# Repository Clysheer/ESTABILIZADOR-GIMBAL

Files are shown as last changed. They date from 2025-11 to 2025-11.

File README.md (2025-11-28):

# ESTABILIZADOR-GIMBAL

Proyecto de gimbal de tres ejes con Arduino Nano, IMU MPU6050 y servos SG90. Incluye PCB diseñada, firmware en C y estructura 3D en PLA. Estabiliza una cámara ligera compensando ±45° con un error menor a 3°, validando el control PID implementado.

## Introducción

El objetivo principal de este trabajo fue diseñar y construir un gimbal electrónico de tres ejes capaz de mantener una cámara estable, compensando los movimientos involuntarios del usuario. Los gimbals son ampliamente utilizados en drones, cámaras portátiles y equipos de filmación profesional, debido a su capacidad para estabilizar la imagen incluso en condiciones dinámicas. La motivación para desarrollar este proyecto surgió de la necesidad creciente de capturar tomas fluidas y sin vibraciones, especialmente en aplicaciones audiovisuales y sistemas aéreos no tripulados.

El desarrollo del gimbal permitió integrar y aplicar múltiples conocimientos adquiridos a lo largo de la tecnicatura, tales como electrónica analógica y digital, diseño de circuitos impresos (PCB), programación de microcontroladores, control automático y procesamiento de señales provenientes de sensores. Este enfoque interdisciplinario hizo posible comprender de manera global cómo distintos sistemas electrónicos pueden trabajar en conjunto para resolver un problema real.

Desde un punto de vista teórico, la construcción del gimbal implicó estudiar conceptos fundamentales de análisis y control de sistemas dinámicos. Para lograr una estabilización eficiente fue necesario comprender el funcionamiento de sensores inerciales (IMU), específicamente el MPU6050, que combina un acelerómetro y un giroscopio de 3 ejes. Estos sensores permiten obtener información sobre la aceleración y la velocidad angular del dispositivo, datos que deben ser filtrados y procesados para estimar correctamente la orientación de la cámara. Se analizaron filtros complementarios y técnicas básicas de fusión sensorial para mejorar la precisión y reducir el ruido de las mediciones.

Otro aspecto central del estudio fue el control PID (Proporcional, Integral y Derivativo), un algoritmo clásico en sistemas de control realimentados. Fue necesario comprender su funcionamiento, las funciones de cada uno de sus términos y cómo su ajuste influye directamente en la estabilidad y velocidad de respuesta del sistema. Se realizaron análisis teóricos sobre estabilidad, amortiguamiento, respuesta al escalón y efectos de la sintonización de parámetros Kp, Ki y Kd. Este controlador permitió corregir en tiempo real la diferencia entre la posición deseada y la posición medida, generando las señales necesarias para ajustar los ángulos de los servomotores.

Asimismo, se estudiaron los principios de funcionamiento de los servomotores, particularmente su control mediante modulación por ancho de pulso (PWM). Se analizaron sus limitaciones mecánicas y eléctricas, torque disponible, velocidad de respuesta y resolución angular. También se evaluaron distintos configuraciones mecánicas y de soporte para garantizar la correcta transmisión del movimiento.

La estructura mecánica del gimbal se diseñó mediante software CAD y luego fue fabricada mediante impresión 3D en PLA. Esto permitió estudiar conceptos de diseño mecánico, peso, distribución de masa, centro de gravedad y rigidez estructural, factores claves para garantizar que el sistema pueda estabilizarse correctamente sin introducir vibraciones.

En conjunto, este proyecto representó una integración completa de teoría y práctica, abarcando áreas como control automático, electrónica digital, diseño de hardware, programación embebida y fabricación mecánica. El resultado final fue un sistema funcional capaz de estabilizar una cámara ligera, demostrando la importancia de la combinación entre conocimientos teóricos y aplicaciones prácticas.

### Objetivos específicos
- Diseñar y construir el circuito de control de los motores, integrando los servomotores y la electrónica necesaria para su funcionamiento.
- Adquirir y procesar los datos del sensor inercial MPU6050 mediante comunicación I2C.
- Implementar un algoritmo de control PID capaz de mantener la posición estable en los tres ejes.
- Diseñar, modelar e imprimir en 3D la estructura mecánica que sostiene la cámara y los motores.
- Integrar hardware, software y mecánica en un único sistema funcional.

Se realizaron ajustes para poder tener los 3 servos bien colocados.

## Descripción del proyecto

### ¿Qué es un Gimbal?

Un gimbal es un sistema de suspensión que permite mantener un objeto (como una cámara) estable y nivelado mientras se mueve. Utiliza motores o servomotores para contrarrestar los movimientos no deseados y estabilizar el objeto en cuestión. En este caso, el gimbal de 3 ejes se utiliza para estabilizar una cámara pequeña o dispositivo similar durante los movimientos en los tres ejes principales: Yaw (giro horizontal), Pitch (inclinación vertical) y Roll (rotación lateral).

En lugar de usar un sistema mecánico pesado, un gimbal moderno utiliza sensores electrónicos y motores controlados electrónicamente para realizar ajustes en tiempo real. Esto permite una estabilización más precisa y dinámica, ideal para aplicaciones como la grabación de videos o fotografía aérea, donde la estabilidad es crucial.

### Componentes principales del Gimbal

#### Servos
En este proyecto, se usan tres servomotores para controlar el movimiento de la cámara en los tres ejes. Los servos son motores de corriente continua con un mecanismo de control que permite ajustar su ángulo de forma precisa. Cada servo se controla mediante una señal de modulación por ancho de pulso (PWM), donde el ancho del pulso determina el ángulo del servo.

Los servos tienen la ventaja de ser fáciles de controlar mediante una señal PWM, lo que los hace ideales para proyectos como este, donde se requiere un control preciso de los movimientos. Sin embargo, los servos también tienen limitaciones en cuanto a la velocidad y torque, lo que debe ser considerado al diseñar el gimbal.

#### MPU6050 (Sensor IMU)
El MPU6050 es un sensor de movimiento que combina un acelerómetro de 3 ejes y un giroscopio de 3 ejes. Este sensor es capaz de medir la aceleración y la velocidad angular en los tres ejes del espacio (X, Y y Z). Se utiliza para detectar el movimiento de la cámara y proporcionar información precisa sobre su orientación en el espacio.

- **Acelerómetro**: mide la aceleración en los tres ejes, lo que ayuda a detectar la inclinación de la cámara con respecto a la gravedad.
- **Giroscopio**: mide la velocidad angular, es decir, la rotación de la cámara en cada uno de los ejes.

La información de estos dos sensores se procesa para calcular la orientación actual de la cámara. La combinación de ambos datos (acelerómetro y giroscopio) permite tener una estimación más precisa del movimiento, ya que cada sensor compensa las limitaciones del otro.

En el proyecto, el MPU6050 se conecta al Arduino a través del protocolo I2C, lo que permite transmitir los datos del sensor con solo dos cables: uno para la señal de reloj (SCL) y otro para la señal de datos (SDA). Estos datos se usan para calcular el ángulo de inclinación de la cámara y se pasan al algoritmo de control PID que ajusta los servos para mantener la estabilización.

#### Arduino
El Arduino es el cerebro del sistema, responsable de recibir los datos del sensor MPU6050 y procesarlos para calcular los ajustes que deben realizarse en los servos. El Arduino, en este caso, actúa como un controlador en tiempo real que implementa un algoritmo de control PID para mantener los ángulos de la cámara estables.

El microcontrolador Arduino UNO se usa por su simplicidad, facilidad de programación y la amplia cantidad de librerías disponibles, que simplifican el trabajo con el sensor MPU6050 y el control de los servos. A través de las señales PWM generadas por el Arduino, se controla el ángulo de cada servo, asegurando que la cámara mantenga la orientación deseada en cada momento.

#### Step-up Converter (Ajuste de voltaje)
Para alimentar la placa del Arduino y los servos, se utiliza un step-up converter. Dado que los servos y el Arduino requieren una tensión de 5V, pero el sistema está alimentado por una batería Li-Po de 3.7V, es necesario usar un step-up para elevar la tensión de la batería hasta los 5V necesarios para el funcionamiento del sistema.

Un step-up converter (convertidor elevador) es un tipo de fuente de alimentación DC-DC que convierte una entrada de baja tensión (en este caso, 3.7V) a una salida de mayor tensión (5V). Esto es crucial, ya que los servos y el Arduino no funcionarían correctamente con 3.7V, ya que ambos requieren una tensión constante de 5V. El step-up también asegura que la energía se entregue de forma eficiente, sin perder demasiada potencia.

### Control PID
El control PID (Proporcional, Integral, Derivativo) es un algoritmo que se utiliza para mantener la cámara en una posición estable. Este tipo de control en lazo cerrado ajusta continuamente la salida (en este caso, el movimiento de los servos) en función de la diferencia entre el valor actual y el valor deseado.

- **Proporcional (P)**: Compara la diferencia (error) entre el ángulo actual y el deseado. Cuanto mayor es el error, mayor será la corrección aplicada.
- **Integral (I)**: Suma el error a lo largo del tiempo, lo que ayuda a corregir pequeños desajustes acumulados.
- **Derivativo (D)**: Analiza la tasa de cambio del error, ayudando a reducir oscilaciones y hacer que el sistema sea más estable.

El objetivo del PID es ajustar los servos en tiempo real para que la cámara mantenga la orientación correcta, minimizando el error de estabilización. Los parámetros Kp, Ki y Kd se ajustan mediante pruebas para lograr una respuesta estable y rápida.

### Funcionamiento del Gimbal
El proceso de estabilización del gimbal funciona de la siguiente manera:

1. **Lectura del sensor**: El MPU6050 mide constantemente la aceleración y la velocidad angular de la cámara.
2. **Cálculo de los ángulos**: Los datos del sensor se procesan en el Arduino para calcular el ángulo de inclinación en los tres ejes.
3. **Control PID**: El algoritmo PID calcula el error entre el ángulo actual y el deseado (normalmente 0° en todos los ejes).
4. **Ajuste de los servos**: El Arduino ajusta los servos mediante señales PWM para contrarrestar cualquier movimiento no deseado y estabilizar la cámara.

### Limitaciones y Mejoras
El uso de servos para este tipo de proyecto tiene algunas limitaciones, como el torque limitado y la velocidad de respuesta. Si los movimientos son muy rápidos o fuertes, los servos podrían no ser lo suficientemente rápidos para corregir la orientación a tiempo. Sin embargo, para cámaras pequeñas y movimientos suaves, los servos proporcionan una solución económica y fácil de implementar.

Como posible mejora, se podría usar motores brushless o stepper motors en lugar de servos, ya que ofrecen mayor torque y velocidad. Sin embargo, esto complicaría el diseño y el control del sistema.

### Lista de componentes y precios estimados
- Arduino Nano - 8000
- MPU6050 - 4500
- 3 Servomotores - 2300 c/u
- Step-up LM2596 - 2900
- 4 JST - 200 c/u
- Borneras - 100 c/u
- Pineras hembra - 1800
- Filamento PLA para diseño 3D - 19.000 x kg (50 grs usados)
- Tornillos - 500
- Cables de interconexión - 2000
- Batería de litio 3,7v - 3500
- **Precio estimado: 27.000 a 30.000**

## SOFTWARE

El software desarrollado para el gimbal electrónico de 3 ejes se encarga de leer los datos del sensor inercial MPU6050, procesarlos mediante algoritmos de filtrado, calcular los ángulos de orientación y ejecutar un control PID para ajustar la posición de los servomotores SG90 en tiempo real. El objetivo del software es garantizar que la cámara permanezca estable aun cuando el usuario realice movimientos bruscos.

El firmware se implementó en lenguaje C/C++ utilizando el entorno de Arduino IDE y emplea librerías específicas para el manejo del sensor y los servos. Toda la lógica del control está optimizada para funcionar en un microcontrolador de recursos limitados como el Arduino Nano.

### Arquitectura general del software
El software se divide en los siguientes módulos principales:
1. Inicialización del sistema
2. Lectura del sensor MPU 6050 (acelerómetro + giroscopio)
3. Procesamiento y filtrado de datos (filtro complementario)
4. Cálculo de los ángulos de orientación (Roll, Pitch, Yaw)
5. Control PID para cada eje
6. Generación de señales PWM para los servomotores
7. Bucle principal (loop) en tiempo real

Diagrama de flujo

### Descripción detallada de cada bloque

#### 3.1. Inicialización del sistema
En esta etapa se configuran:
- La comunicación I2C (Wire.h)
- La velocidad de muestreo del MPU6050
- Los pines y librerías de los servos
- Variables internas del PID
- Temporizadores para cálculos en tiempo real

El sistema queda listo para funcionar dentro del loop principal.

#### 3.2. Lectura del sensor MPU6050
El sensor proporciona:
- Aceleración (Ax, Ay, Az)
- Velocidad angular (Gx, Gy, Gz)

La lectura se realiza a través de I2C y se normaliza a unidades físicas:
- Acelerómetro → g (9.81 m/s²)
- Giroscopio → °/s (grados por segundo)

Estas señales suelen contener ruido, por eso necesitan filtrado.

#### 3.3. Filtrado y Fusión de Datos
Para obtener una estimación precisa de los ángulos se utiliza un filtro complementario, que combina:
- Los datos estables del acelerómetro
- La rapidez y suavidad del giroscopio

El filtro realiza:
Ángulo = 0.98*(Ángulo + gyro*dt) + 0.02*(Accel)

Este método reduce vibraciones y evita errores acumulados.

#### 3.4. Cálculo de Ángulos (Roll, Pitch y Yaw)
Del acelerómetro se obtienen roll y pitch mediante trigonometría:
- Roll = atan2(Ay, Az)
- Pitch = atan2(-Ax, sqrt(Ay² + Az²))

Yaw se obtiene integrando el giroscopio Gz.
Cada ángulo se estabiliza mediante el filtro complementario.

#### 3.5. Control PID
El PID compara la posición actual (sensor) con la deseada (0° para estabilización).
Para cada eje se calcula:
- Error: diferencia entre ángulo deseado y ángulo real
- P: corrige el error instantáneo
- I: acumula errores pequeños
- D: suaviza y evita oscilaciones

El PID entrega un valor corregido que indica cuánto debe moverse cada servo.

#### 3.6. Señales PWM a los Servomotores
Arduino genera pulsos PWM con:
- Frecuencia: 50 Hz
- Ancho del pulso: 500–2500 µs

El ancho del pulso define la posición del servo.
Ejemplo:
- 1000 µs → -45º
- 1500 µs → 0º
- 2000 µs → +45º

#### 3.7. Loop principal
Se ejecuta unas 200 a 400 veces por segundo, realizando:
1. Lectura MPU6050
2. Filtrado de señales
3. PID
4. PWM
5. Estabilización

Esto permite una respuesta rápida del gimbal.

### Flujo de funcionamiento del software (texto para informe)
1. El sistema inicia y configura todos los módulos.
2. El microcontrolador lee las mediciones del MPU6050.
3. Los datos se filtran para obtener ángulos limpios.
4. Se calcula la orientación de la cámara.
5. El PID determina cuánto corregir la posición.
6. Los servos se ajustan mediante PWM.
7. El proceso se repite en tiempo real.

### Código PID

```cpp
#include <Wire.h>
#include <Servo.h>
#include "I2Cdev.h"
#include "MPU6050.h"

MPU6050 mpu;
Servo servoRoll, servoPitch, servoYaw;

// Ángulos filtrados
float roll = 0, pitch = 0, yaw = 0;

// Offsets del giroscopio (se calibran en setup)
float gyroXoffset = 0, gyroYoffset = 0, gyroZoffset = 0;

// Setpoints (posición deseada del gimbal)
float setpointRoll = 0;
float setpointPitch = 0;
float setpointYaw = 0;

// Variables PID
float errorRoll, errorPitch, errorYaw;
float prevErrorRoll = 0, prevErrorPitch = 0, prevErrorYaw = 0;
float integralRoll = 0, integralPitch = 0, integralYaw = 0;

// Ganancias PID (ajustar según pruebas)
float Kp = 2.0;
float Ki = 0.5;
float Kd = 1.0;

unsigned long lastTime = 0;
float dt = 0.01;

// Factor del filtro complementario (0.98 → giroscopio domina, 0.02 → acelerómetro corrige)
const float alpha = 0.98;

void setup() {
    Serial.begin(9600);
    Wire.begin();
    
    // Inicializar MPU6050
    Serial.println("Inicializando MPU6050...");
    mpu.initialize();
    if (!mpu.testConnection()) {
        Serial.println("Error: no se detecta MPU6050!");
        while (1);
    }
    
    // Calibrar giroscopio (promedio en reposo)
    Serial.println("Calibrando giroscopio...");
    long gxSum = 0, gySum = 0, gzSum = 0;
    for (int i = 0; i < 2000; i++) {
        int16_t ax, ay, az, gx, gy, gz;
        mpu.getMotion6(&ax, &ay, &az, &gx, &gy, &gz);
        gxSum += gx;
        gySum += gy;
        gzSum += gz;
        delay(2);
    }
    gyroXoffset = gxSum / 2000.0;
    gyroYoffset = gySum / 2000.0;
    gyroZoffset = gzSum / 2000.0;
    Serial.println("Calibración completa.");
    
    // Servos
    servoRoll.attach(9);
    servoPitch.attach(10);
    servoYaw.attach(11);
    servoRoll.write(90);
    servoPitch.write(90);
    servoYaw.write(90);
    
    lastTime = millis();
}

void loop() {
    unsigned long now = millis();
    dt = (now - lastTime) / 1000.0;
    if (dt <= 0) dt = 0.01;
    lastTime = now;
    
    // Leer datos del MPU6050
    int16_t ax, ay, az, gx, gy, gz;
    mpu.getMotion6(&ax, &ay, &az, &gx, &gy, &gz);
    
    // Convertir giroscopio a º/s (sensibilidad: 131 LSB/(º/s))
    float gyroXrate = (gx - gyroXoffset) / 131.0;
    float gyroYrate = (gy - gyroYoffset) / 131.0;
    float gyroZrate = (gz - gyroZoffset) / 131.0;
    
    // Calcular ángulos con acelerómetro
    float accPitch = atan2(ax, sqrt(ay * ay + az * az)) * 180.0 / PI;
    float accRoll  = atan2(ay, sqrt(ax * ax + az * az)) * 180.0 / PI;
    
    // Filtro complementario
    pitch = alpha * (pitch + gyroXrate * dt) + (1 - alpha) * accPitch;
    roll  = alpha * (roll - gyroYrate * dt) + (1 - alpha) * accRoll;
    yaw += gyroZrate * dt; // yaw solo con giroscopio (deriva un poco con el tiempo)
    
    // --- PID Roll ---
    errorRoll = setpointRoll - roll;
    integralRoll += errorRoll * dt;
    float derivativeRoll = (errorRoll - prevErrorRoll) / dt;
    float outputRoll = Kp * errorRoll + Ki * integralRoll + Kd * derivativeRoll;
    prevErrorRoll = errorRoll;
    
    // --- PID Pitch ---
    errorPitch = setpointPitch - pitch;
    integralPitch += errorPitch * dt;
    float derivativePitch = (errorPitch - prevErrorPitch) / dt;
    float outputPitch = Kp * errorPitch + Ki * integralPitch + Kd * derivativePitch;
    prevErrorPitch = errorPitch;
    
    // --- PID Yaw ---
    errorYaw = setpointYaw - yaw;
    integralYaw += errorYaw * dt;
    float derivativeYaw = (errorYaw - prevErrorYaw) / dt;
    float outputYaw = Kp * errorYaw + Ki * integralYaw + Kd * derivativeYaw;
    prevErrorYaw = errorYaw;
    
    // Convertir a servo (90 = centro)
    int servoRollVal  = constrain(90 + outputRoll, 0, 180);
    int servoPitchVal = constrain(90 + outputPitch, 0, 180);
    int servoYawVal   = constrain(90 + outputYaw, 0, 180);
    
    servoRoll.write(servoRollVal);
    servoPitch.write(servoPitchVal);
    servoYaw.write(servoYawVal);
    
    // Debug
    Serial.print("Roll: "); Serial.print(roll);
    Serial.print(" | Pitch: "); Serial.print(pitch);
    Serial.print(" | Yaw: "); Serial.print(yaw);
    Serial.print(" | S_R: "); Serial.print(servoRollVal);
    Serial.print(" | S_P: "); Serial.print(servoPitchVal);
    Serial.print(" | S_Y: "); Serial.println(servoYawVal);
    
    delay(10); // ~100 Hz
}
```

## Hardware

### DISEÑO ELECTRÓNICO Y ESQUEMÁTICO (MÓDULOS Y CIRCUITO PRINCIPAL)

Objetivo de la etapa: definir la arquitectura eléctrica del gimbal y generar el esquemático que interconecta MCU, IMU, drivers de potencia, alimentación y servos.

#### Módulos utilizados
- Microcontrolador: Arduino Nano (ATmega328P)
- IMU: MPU6050 (Acelerómetro + Giroscopio 3-ejes)
- Actuadores: 3 × Servomotores SG90 (PWM)
- Regulación: Step-up DC-DC (LM2596 o equivalente)
- Alimentación: Batería LiPo 1S (3.7 V)
- Conectores: JST 3/4 pines, pines hembra 2.54 mm
- Indicadores: LED de alimentación y pulsadores de calibración (opcional)

#### Esquema eléctrico (descripción para replicar)
- V_BAT → STEPUP_IN
- STEPUP_OUT 5V → RAIL_5V (alimentación para Arduino y servos)
- GND común a batería, step-up, servos y Arduino
- Arduino (5V) alimenta: VIN o 5V según modelo (en Nano usar pin 5V)
- MPU6050: SDA → A4 (I2C SDA), SCL → A5 (I2C SCL), VCC → 3.3V o 5V (según breakout) – usar 3.3V si es breakout sin regulador; comprobar tolerancias. GND → GND
- Servos: señal → pines PWM del Arduino (ej: D3, D5, D6), Vcc → RAIL_5V, GND → GND
- Condensadores de desacople: 100µF en entrada y salida del step-up, 0.1µF cerámico cerca del MCU y del IMU
- Fusible polímero o PTC en línea de batería (recomendado)

Aplicación: el esquema se usa para fabricar la PCB que interconecta todos los módulos con vías limpias, anclajes mecánicos para el ensamblado y header para conexión de la estructura 3D.

Esquemático PCB

### DESCRIPCIÓN DE CADA ETAPA DE CONSTRUCCIÓN

#### Etapa A — Montaje y prueba de la alimentación
- Módulo: Step-up LM2596, fusible PTC, conector batería.
- Schematic focal: entrada batería → PTC → condensadores → LM2596 → 5V rail → protecciones.
- Pruebas: medir 5V sin carga y con servos conectados; verificar rizado < 100 mV.
- Aplicación: suministrar energía estable a servos y MCU.

#### Etapa B — Comunicación y sensor IMU
- Módulo: MPU6050 (I2C).
- Schematic focal: pull-ups I2C, decoupling, y test pads.
- Pruebas: leer registros WHO_AM_I, comprobar aceleraciones en reposo.
- Aplicación: proveer mediciones de aceleración y velocidad angular.

#### Etapa C — Control y firmware básico
- Módulo: Arduino Nano + firmware base (I2C, lectura IMU, serial).
- Schematic focal: pines de programación, led de status.
- Pruebas: mostrar datos por Serial, verificar lecturas estables.
- Aplicación: plataforma de prueba para algoritmos.

#### Etapa D — Actuadores y control PID
- Módulo: 3× SG90, headers de servo, filtros de alimentación.
- Schematic focal: ruta de alimentación de servos y pines PWM.
- Pruebas: enviar ángulos de prueba, medir respuesta y tiempos.
- Aplicación: ajuste de Kp, Ki, Kd y verificación de comportamiento.

#### Etapa E — Integración mecánico-eléctrica
- Módulo: estructura 3D en PLA (soportes, anclajes de servos) y montaje final de PCB.
- Schematic focal: puntos de anclaje, orificios M3, distancias.
- Pruebas: montaje mecánico, balanceo de cargas, centrado de masas.
- Aplicación: ver comportamiento dinámico real.

#### Etapa F — Calibración, pruebas finales y documentación
- Módulo: software de calibración y parámetros finales, manual de usuario.
- Schematic focal: puntos de ajuste (trim) y header de calibración.
- Pruebas: medición de error final (<3°), endurance tests.
- Aplicación: entrega del proyecto y repositorio.

### ESPECIFICACIONES TÉCNICAS (DETALLADAS)

#### Especificaciones generales
- Ejes: 3 (Yaw, Pitch, Roll)
- Rango de corrección: ±45° (por eje)
- Error de estabilización: < 3° (según pruebas)
- Latencia de control objetivo: < 20 ms
- Tasa de muestreo IMU: 200–500 Hz
- Alimentación: 1S LiPo 3.7 V → Step-up a 5 V
- Consumo estimado: 500 mA (reposo) – hasta 2 A con 3 servos en carga

#### Componentes críticos y parámetros
- MPU6050: resolución ±2g/±250°/s (configurable)
- Servos SG90: torque 1.6–2.2 kg·cm, velocidad ~0.1 s/60°
- Step-up LM2596: efficiency ~80–90%, corriente máxima 3 A (con disipación adecuada)
- MCU: ATmega328P @16 MHz, memoria suficiente para PID y filtros

Especificaciones técnicas

## DISEÑO 3D EN FUSION 360 (PARA LA ESTRUCTURA EN PLA)

Objetivo: diseñar la estructura que aloje la cámara y los servos, permita montaje seguro y tenga puntos de anclaje para la PCB y la batería.

### Flujo en Fusion 360
1. Esbozo (Sketch): definir dimensiones base del soporte de cámara y ubicación de servos.
2. Modelado: extruir y crear cortes, añadir nervaduras para rigidez.
3. Soportes y anclajes: crear orificios M3 y bosses para inserción de tuercas empotradas.
4. Verificación de interferencias: usar la herramienta de assemble para montar servos y cámara y verificar colisiones.
5. Exportar: generar archivos STL por cada pieza y PDFs con dimensiones.

### Parámetros de diseño recomendados
- Espesor mínimo de paredes: 2.5–3 mm (para PLA estructural).
- Bosses para tuercas: altura 3–4 mm, diámetro 2 mm mayor que el tornillo.
- Holgura para encajes: 0.2–0.4 mm según precisión de impresora.
- Zona de montaje de servos: ajuste de 0.5–1 mm si el servo se inserta a presión.
- Anclajes para PCB: 4 puntos con separación

### Configuraciones de impresión (PLA) sugeridas
- Layer height: 0.20 mm
- Infill: 20% (rectilinear o gyroid para rigidez)
- Perímetro: 3 shells
- Temp extrusor: 200–210 °C (según filamento)
- Temp cama: 50–60 °C
- Velocidad: 40–60 mm/s
- Soportes: donde haya voladizos > 45°
- Post-procesado: lijado y, si es necesario, encolado con epoxi para uniones críticas

### Pruebas mecánicas
- Balanceo: colocar la cámara y medir centro de gravedad; ajustar contrapesos si hace falta
- Rigidez: ensayo de vibración manual y comprobar resonancias con la IMU (picos en frecuencia)

### Diseño Montado y finalizado
Diseño Final

### Proceso de diseño
Proceso de diseño

### Primer Prototipo
Primer Prototipo

### Diseño Final
Diseño Final

## Diagrama de gantt, reparto de tareas y tiempos
Diagrama de Gantt

## Conclusiones

El desarrollo del gimbal electrónico de tres ejes permitió integrar conocimientos de electrónica, programación, control, diseño 3D y fabricación de PCBs, culminando en un sistema funcional capaz de estabilizar una cámara ligera frente a movimientos no deseados. A lo largo del proyecto se logró implementar un sistema de control basado en un algoritmo PID, utilizando un sensor inercial MPU6050 y servomotores SG90, todo gestionado por un microcontrolador Arduino Nano.

La estructura mecánica se diseñó íntegramente en Fusion 360 y se imprimió en PLA, logrando un soporte liviano, rígido y adecuado para alojar los motores y la cámara. Por otro lado, el diseño y fabricación de la PCB en KiCad permitió reducir el cableado, mejorar la robustez del sistema y optimizar la distribución de cada componente electrónico.

Las pruebas realizadas mostraron que el sistema puede estabilizar la cámara con un error angular reducido, incluso frente a perturbaciones suaves y movimientos moderados. Si bien los servomotores tienen limitaciones de torque y velocidad, el desempeño general fue satisfactorio para las condiciones planteadas en este proyecto.

Este trabajo permitió consolidar habilidades adquiridas durante la tecnicatura, especialmente en control, sensores, programación, diseño CAD/CAE y prototipado electrónico. Asimismo, evidenció la importancia de integrar correctamente la mecánica, la electrónica y el software para obtener un sistema mecatrónico funcional y estable.

## Posibles mejoras y líneas de trabajo futuras

Si bien el gimbal cumple con los objetivos iniciales, existen varias mejoras que podrían implementarse para obtener un sistema más robusto, preciso y profesional:

### 1. Reemplazo del Arduino Nano por un ESP32
El ESP32 permitiría ampliar significativamente las capacidades del sistema:
- Mayor poder de procesamiento para ejecutar filtros más avanzados (Kalman, Madgwick).
- Control de motores más preciso gracias a PWM de alta resolución.
- Conectividad WiFi y Bluetooth para control remoto de la cámara.
- Posibilidad de transmisión de datos, telemetría o configuración desde una app.

Además, el mayor rendimiento del ESP32 permitiría implementar estabilización en tiempo real con menor latencia.

### 2. Uso de motores brushless con drivers gimbal (BGC)
Los servos SG90 son económicos pero limitados. Cambiar a motores brushless específicos para gimbal permitiría:
- Movimientos más suaves y continuos.
- Mayor torque disponible.
- Mayor velocidad de respuesta.
- Ausencia de vibraciones características del servo.

Con esto se lograría una estabilización semi-profesional comparable a la de los gimbals comerciales.

### 3. Implementación de un filtro de fusión de sensores avanzado
En lugar del filtrado simple basado en el MPU6050, se podría agregar:
- Filtro de Kalman
- Filtro Madgwick o Mahony

Esto mejoraría la precisión en la estimación de los ángulos, sobre todo en presencia de vibraciones o cambios bruscos.

### 4. Rediseño estructural optimizado
Usando Fusion 360 se podrían:
- Reducir peso aplicando aligeramientos en zonas no críticas.
- Mejorar la ergonomía del soporte.
- Aumentar la rigidez de la estructura para reducir resonancias.
- Integrar directamente soportes para cableado interno.

Un diseño más optimizado también permitiría mejorar la autonomía de la batería.

### 5. Integración de una batería de mayor capacidad y sistema de carga
Se recomienda:
- Agregar un módulo de carga TP4056.
- Mejorar la autonomía utilizando una batería Li-Ion 18650.
- Incorporar un indicador de nivel de batería en la PCB.

Esto haría que el gimbal sea más cómodo y seguro de utilizar.

### 6. Agregar modos de funcionamiento
El software podría ampliarse con funciones más completas:
- Modo "lock": mantiene fija la orientación.
- Modo "follow": sigue el movimiento del usuario suavizado.
- Modo panorámico: giro automático para capturas 360°.
- Configuración mediante Bluetooth o app móvil.

### 7. Integración de una cámara más pesada
Con un rediseño mecánico y motores más potentes se podría admitir:
- Cámaras deportivas (GoPro).
- Cámaras compactas.
- Módulos de visión artificial.

Esto ampliará notablemente su campo de aplicación.

## APÉNDICES

### Apéndice A – Manual de Usuario del Gimbal de 3 Ejes

#### 1. Introducción
Este manual tiene como objetivo indicar al usuario cómo utilizar correctamente el gimbal electrónico de 3 ejes diseñado en este proyecto. Incluye instrucciones de encendido, calibración, operación y mantenimiento básico.

#### 2. Componentes del sistema
El gimbal está compuesto por:
- Estructura 3D impresa (PLA) diseñada en Fusion 360.
- Microcontrolador Arduino Nano (o placa equivalente).
- Sensor inercial MPU6050 (acelerómetro + giroscopio).
- 3 servomotores SG90 para los ejes Pitch, Roll y Yaw.
- Placa PCB personalizada diseñada en KiCad.
- Convertidor Step-Up LM2596 (para elevar la tensión de la batería).
- Batería LiPo/Li-Ion 3.7 V.
- Cableado interno con conectores JST.

#### 3. Puesta en marcha

##### 3.1 Encendido
1. Conectar la batería al sistema.
2. Verificar que el LED del Arduino encienda.
3. Esperar 2–3 segundos para que el MPU6050 se inicialice.
4. Mantener el gimbal quieto mientras se calibra automáticamente.

##### 3.2 Calibración inicial
Durante los primeros segundos:
- El sistema toma valores base de aceleración y giro.
- El PID se ajusta a la postura inicial de la cámara.

Recomendación:
Colocar el gimbal en una superficie estable y evitar movimiento.

#### 4. Operación

##### 4.1 Movimientos
El gimbal estabiliza automáticamente los tres ejes:
- Pitch (inclinación vertical)
- Roll (rotación lateral)
- Yaw (rotación horizontal)

El usuario puede manipular la base mientras el sistema compensa movimientos involuntarios.

##### 4.2 Funcionamiento del sistema
El algoritmo PID calcula en tiempo real la diferencia entre:
- Ángulo deseado (0°)
- Ángulo real medido por el MPU6050

y ajusta los servos inmediatamente.

##### 4.3 Modo de uso recomendado
- Movimientos suaves → mejor estabilización.
- Evitar golpes o vibraciones excesivas.
- Mantener la cámara bien centrada en el soporte.
- No exceder el peso recomendado (ideal: cámaras pequeñas).

#### 5. Mantenimiento

##### 5.1 Mantenimiento eléctrico
- Verificar periódicamente soldaduras y conectores JST.
- Asegurarse de que el LM2596 entregue 5 V estables.
- No utilizar baterías hinchadas o dañadas.

##### 5.2 Mantenimiento mecánico
- Revisar tornillos y soportes 3D.
- Evitar exposición prolongada al sol (PLA puede deformarse).
- Aplicar suavemente lubricación siliconada en los servos si es necesario.

#### 6. Solución de problemas

| Problema | Causa probable | Solución |
|---|---|---|
| El gimbal vibra demasiado | Ganancias PID incorrectas | Ajustar Kp, Ki o Kd |
| Se inclina hacia un lado | Calibración incorrecta | Reiniciar con el gimbal quieto |
| Los servos hacen ruido continuo | Demasiado esfuerzo mecánico | Recentrar la cámara |
| No enciende | Sin alimentación | Revisar batería y LM2596 |
| Movimientos lentos | Servo dañado o bajo torque | Reemplazar servo SG90 |

#### 8. Seguridad
- No conectar la batería al revés.
- Evitar contacto con agua o humedad.
- No operar cerca de objetos frágiles o personas.
- Mantener fuera del alcance de niños.

## BIBLIOGRAFÍA

- Arduino. Arduino Nano Documentation. Arduino.cc.
- Bosch Sensortec. MPU6050 6-axis MotionTracking Device – Datasheet.
- KiCad Project. KiCad EDA Documentation. kicad.org.
- SG90 Micro Servo Motor. Technical Specifications – TowerPro.
- Texas Instruments. LM2596 Step-Down Voltage Regulator Datasheet.
- National Instruments. PID Theory Explained.
- O'Reilly Media. Make: Electronics – Learning Through Discovery.
- Z. Chen & Others. Fundamentals of Inertial Navigation and Inertial Sensors.
- Autodesk. Fusion 360 User Manual. autodesk.com.
- Sebastian Madgwick. An efficient orientation filter for inertial/magnetic sensor arrays.
- R. Isermann. Digital Control Systems. Springer.
- Proteus & KiCad community forums (consultas técnicas).

### Páginas utilizadas para teoría e investigación
- https://www.arduino.cc
- https://kicad.org
- https://randomnerdtutorials.com (ejemplos MPU6050 y ESP32)
- https://makeradvisor.com
- https://electronics-tutorials.ws
- https://invensense.tdk.com/products/motion-tracking/6-axis/mpu-6050

### Bibliografía sugerida para ampliación (opcional)
- Lynch, K. & Park, F. Modern Robotics. Cambridge University Press.
- Craig, J. Introduction to Robotics: Mechanics and Control. Pearson.
- Dorf & Bishop. Modern Control Systems.

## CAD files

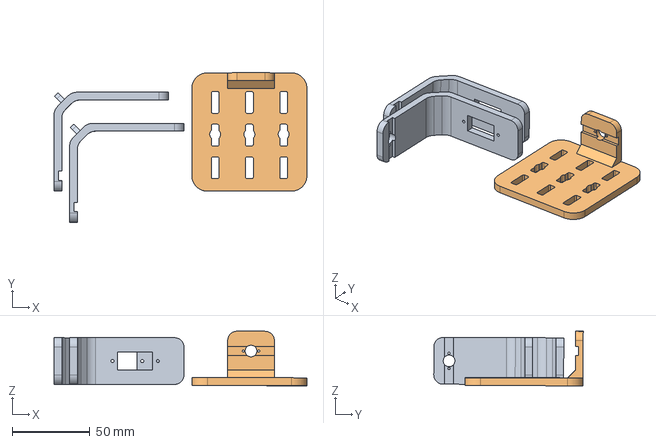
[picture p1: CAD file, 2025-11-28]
3D Model /Modelo formato Step/DIY Gimbal zamba 2.0 -Bases v1.step
162.5 x 96.0 x 35.1 mm
Base 03 - Pitch servo x 2
Top platform

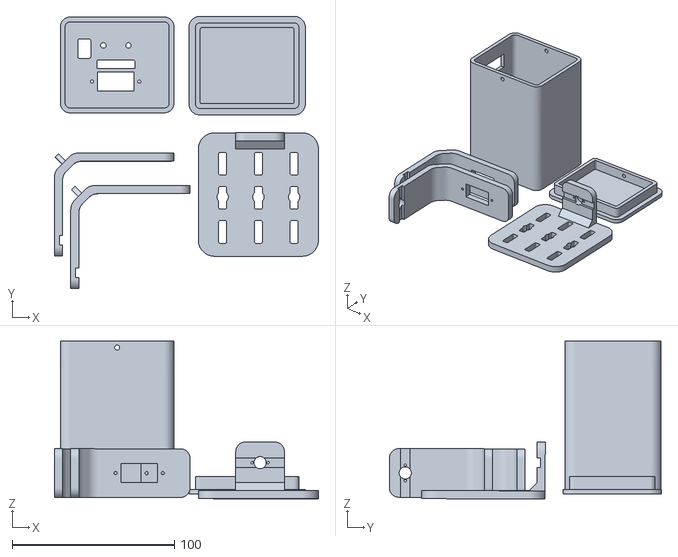
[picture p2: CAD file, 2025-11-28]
3D Model /Modelos formato stl/DIY Gimbal zamba 2 v3.stl
162.5 x 167.7 x 97.2

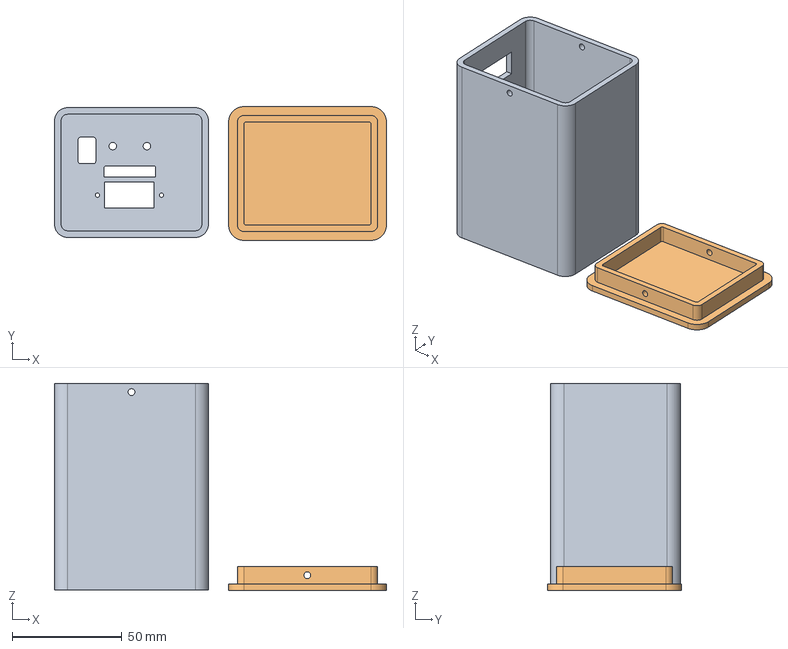
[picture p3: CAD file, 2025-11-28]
3D Model /Modelo formato Step/DIY Gimbal zamba 2.0-Soporte v0.step
150.9 x 60.8 x 94.2 mm
Base 01 - Yaw servo
bottom cover

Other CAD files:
3D Model /Modelo formato Step/DIY Gimbal zamba 2 v3.step
3D Model /Modelos formato stl/DIY Gimbal zamba 2.0 -Bases v1.stl
3D Model /Modelos formato stl/DIY Gimbal zamba 2.0-Soporte v1.stl
3D Model /Modelos Fusion/DIY Gimbal zamba 2.1 v2.f3d

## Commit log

2025-11-28 Create diseño pcb
2025-11-28 Create formatos stl
